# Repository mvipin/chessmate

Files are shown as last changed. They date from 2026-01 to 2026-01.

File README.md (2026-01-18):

# ChessMate - ROS2 Chess Robot






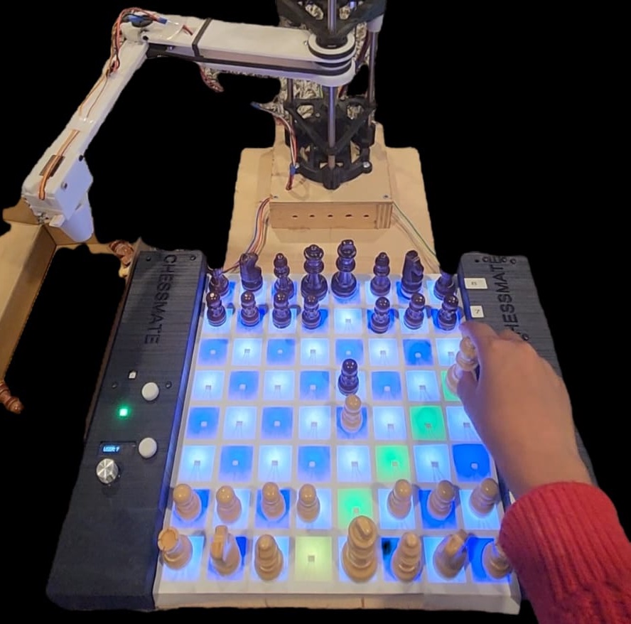
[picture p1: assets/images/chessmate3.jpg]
ChessMate Robot


**An AI chess master with expressive eyes, custom electronics, and a precision arm that will checkmate you with style!**

ChessMate is a fully autonomous chess-playing robot that physically moves pieces on a real chessboard. Built with ROS2, it combines professional-grade chess AI (Stockfish), custom electronics with home-fabricated PCBs, a 3-DOF SCARA robotic arm, and expressive animatronics to create an engaging chess opponent with personality.

## Introduction

### Key Features

| Category | Features |
|---|---|
| **Chess Intelligence** | Stockfish engine integration (skill levels 1-20), real-time move validation, FEN notation tracking, position analysis |
| **Robotic Precision** | 3-DOF SCARA arm (θ1 base, θ2 shoulder, Z height), sub-millimeter positioning accuracy, adaptive gripping, four-corner calibration |
| **Board Sensing** | 64 hall effect sensors, custom CNC-fabricated PCBs, 8×8 NeoPixel LED matrix, real-time move detection |
| **User Interface** | OLED display with rotary encoder, expressive servo-driven eyes, text-to-speech synthesis |
| **Architecture** | Three-controller distributed design (Pi + 2× Pico), topic-based ROS2 communication, mock/real mode support |

---

## Table of Contents

- [Introduction](#introduction)
- [Hardware Architecture](#hardware-architecture)
  - [PCB Design](#pcb-design)
  - [SCARA Arm](#scara-arm)
  - [Animatronics Head](#animatronics-head)
  - [Peripherals](#peripherals)
- [Software Architecture](#software-architecture)
  - [ROS2 Nodes](#ros2-nodes)
    - [chess_engine_server](#chess_engine_server)
    - [arduino_communication](#arduino_communication)
    - [game_management](#game_management)
  - [Active Topics](#active-topics)
  - [Serial Protocol](#serial-protocol)
- [Controllers](#controllers)
  - [ChessBoard Controller](#chessboard-controller)
  - [Robot Controller](#robot-controller)
- [Communication Flow](#communication-flow)
  - [Game Flow State Machine](#game-flow-state-machine)
  - [System Interaction Flows](#system-interaction-flows)
    - [System Initialization Flow](#system-initialization-flow)
    - [Computer Move Execution Flow](#computer-move-execution-flow)
    - [Human Move Detection Flow](#human-move-detection-flow)
    - [LCD Display and Menu Operation Flow](#lcd-display-and-menu-operation-flow)
    - [Robot Animatronics Flow](#robot-animatronics-flow)
- [Getting Started](#getting-started)
- [Testing](#testing)
  - [Overview](#overview)
  - [Test Levels](#test-levels)
  - [Running Tests](#running-tests)
  - [Monitoring & Diagnostics](#monitoring--diagnostics)
  - [Diagnostic Session Example](#diagnostic-session-example)
  - [Troubleshooting](#troubleshooting)
- [Continuous Integration](#continuous-integration)

---

## Hardware Architecture

ChessMate uses a distributed three-controller architecture. Each controller handles specific responsibilities, communicating via serial protocols.

| Controller | Role | Responsibilities |
|---|---|---|
| **Raspberry Pi** | The Brain | Chess engine integration and move calculation, game state management and rule enforcement, audio processing for speech and sound effects, system-wide coordination and safety oversight |
| **Board Controller** | The Senses | Real-time monitoring of all 64 chess piece positions, visual feedback through LED matrix, user interface management (OLED, buttons, rotary encoder), move detection and validation, player interaction handling |
| **Mechanical Controller** | The Body | Precision robotic arm movement control, adaptive gripper operation for different pieces, animatronic facial expressions and eye movements, safety systems and emergency stop coordination, real-time motion execution |

The diagram below shows the physical hardware components and their connections. The Raspberry Pi serves as the central brain, communicating with two Pi Pico microcontrollers via USB serial at 9600 baud. The Board Controller handles all sensing and user interface components, while the Mechanical Controller manages actuation and motion.

```mermaid
graph TB
    subgraph "Raspberry Pi - Main Brain"
        A[Stockfish Engine]
        B[Game Management]
        C[Audio Processing]
    end

    subgraph "Board Controller - Pi Pico"
        D[64 Hall Effect Sensors]
        E[8x8 NeoPixel LED Matrix]
        F[OLED Display + Rotary Encoder]
    end

    subgraph "Mechanical Controller - Pi Pico"
        G[Stepper Motors - Arm]
        H[Servo Motors - Gripper/Eyes]
        I[Limit Switches - Safety]
    end

    A <--> B
    B <--> C
    B <-->|"/dev/ttyACM0 @ 9600 baud"| D
    B <-->|"/dev/ttyACM1 @ 9600 baud"| G
    D --> E
    D --> F
    G --> H
    G --> I
```

### PCB Design

Custom CNC-fabricated PCBs provide the foundation for the chessboard sensing system.

| Specification | Value |
|---|---|
| Sensors | 64 hall effect sensors arranged in 8×8 grid |
| Interface | I2C expanders for efficient GPIO usage |
| Fabrication | CNC-milled PCBs with custom routing |
| Calibration | Baseline recording with threshold-based detection |

**Sensor Calibration:** Place pieces in starting positions → record baseline → set detection thresholds → validate all squares.

#### Chessboard Visuals

| CAD Rendering | Fabricated Chessboard |
|:---:|:---:|
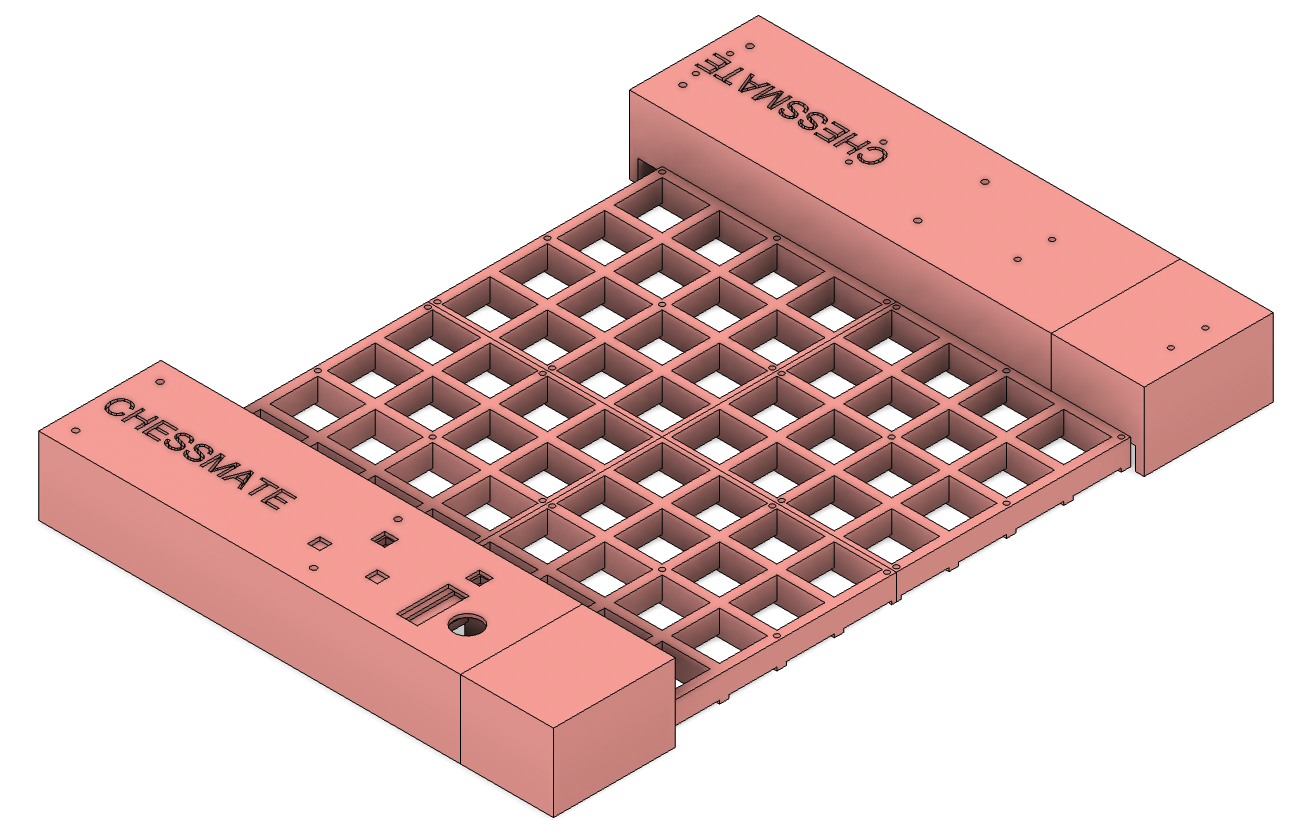
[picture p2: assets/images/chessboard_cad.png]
Chessboard CAD
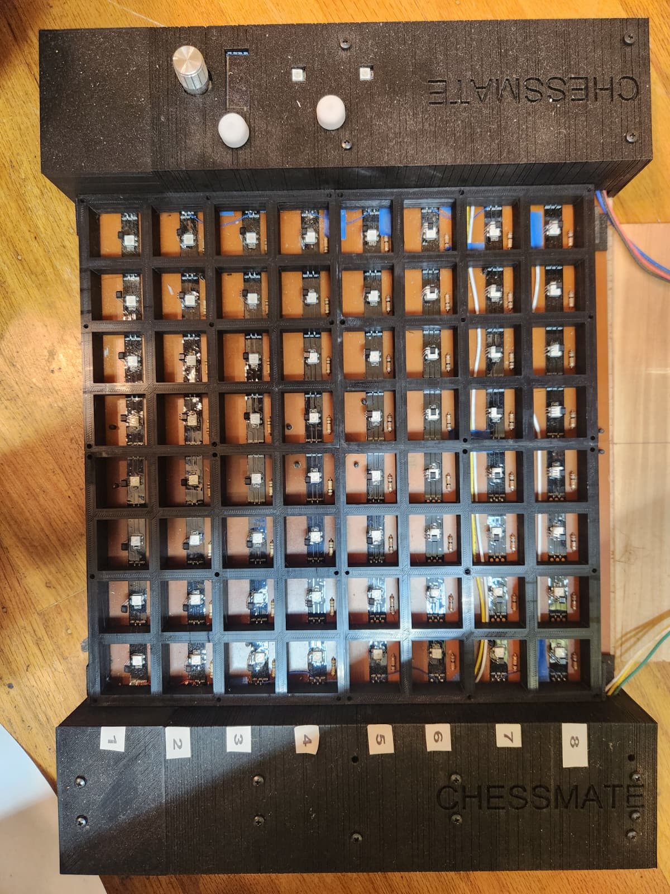
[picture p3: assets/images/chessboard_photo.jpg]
Chessboard Photo
|  |  |
| *3D CAD model showing board layout and sensor placement* | *Assembled chessboard with LED matrix and piece detection* |

| CNC Isolation-Milled PCB |
|:------------------------:|
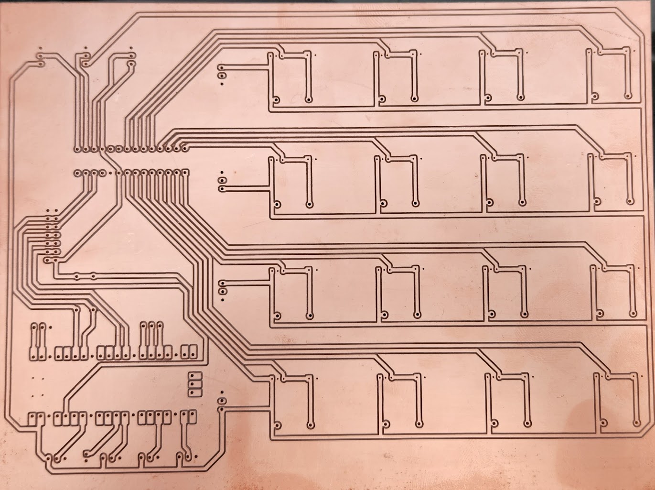
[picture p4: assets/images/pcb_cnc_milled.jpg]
PCB Photo
|  |
| *Custom PCB with hall effect sensors created using CNC isolation milling* |

<!--
TODO: Add actual image files to assets/images/ directory:
- chessboard_cad.png: CAD rendering of complete chessboard design
- chessboard_photo.jpg: Photo of assembled/fabricated chessboard
- pcb_cnc_milled.jpg: Close-up photo of CNC isolation-milled PCB with hall effect sensors
-->

### SCARA Arm

The 3-DOF SCARA (Selective Compliance Assembly Robot Arm) provides precise piece manipulation across the entire chessboard using two rotational joints plus one linear axis.

| Specification | Value |
|---|---|
| Arm Type | 3-DOF SCARA |
| Joint 1 (θ1) | Base rotation - positions arm radially |
| Joint 2 (θ2) | Shoulder rotation - extends/retracts reach |
| Joint 3 (Z) | Vertical translation - raises/lowers entire arm |
| Workspace | Full 8×8 chessboard coverage |
| Repeatability | Sub-millimeter positioning accuracy |
| Actuation | NEMA 17 steppers with microstepping |
| Gripper | Servo-controlled adaptive gripping |

**Arm Calibration:** Home position via limit switches → four-corner board registration → 64-point square mapping → EEPROM storage.

#### SCARA Arm Visuals

| CAD Rendering | Assembled Arm |
|:---:|:---:|
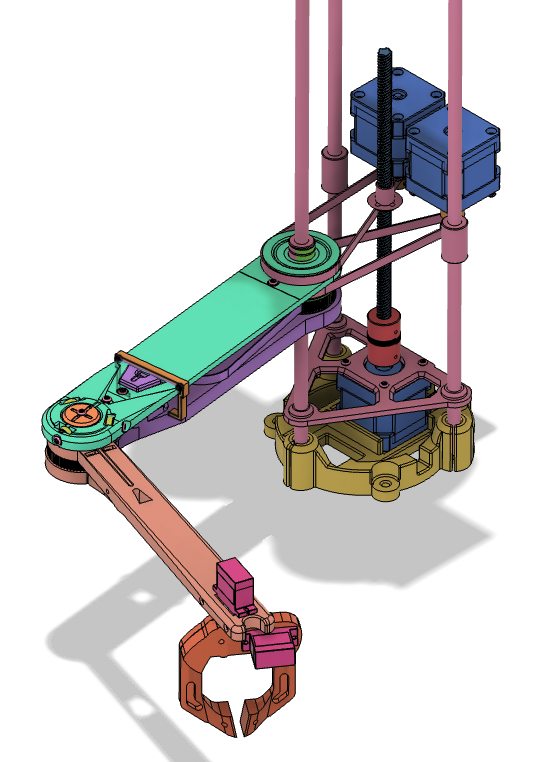
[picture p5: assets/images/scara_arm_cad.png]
SCARA CAD
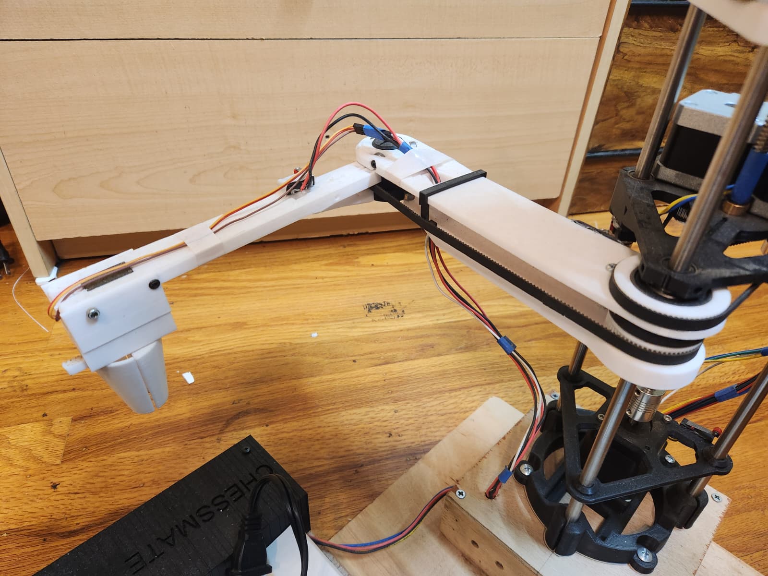
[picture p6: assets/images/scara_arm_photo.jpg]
SCARA Photo
|  |  |
| *3-DOF SCARA arm CAD model showing joint configuration* | *Assembled robotic arm mounted on chess platform* |

| Gripper Mechanism |
|:-----------------:|
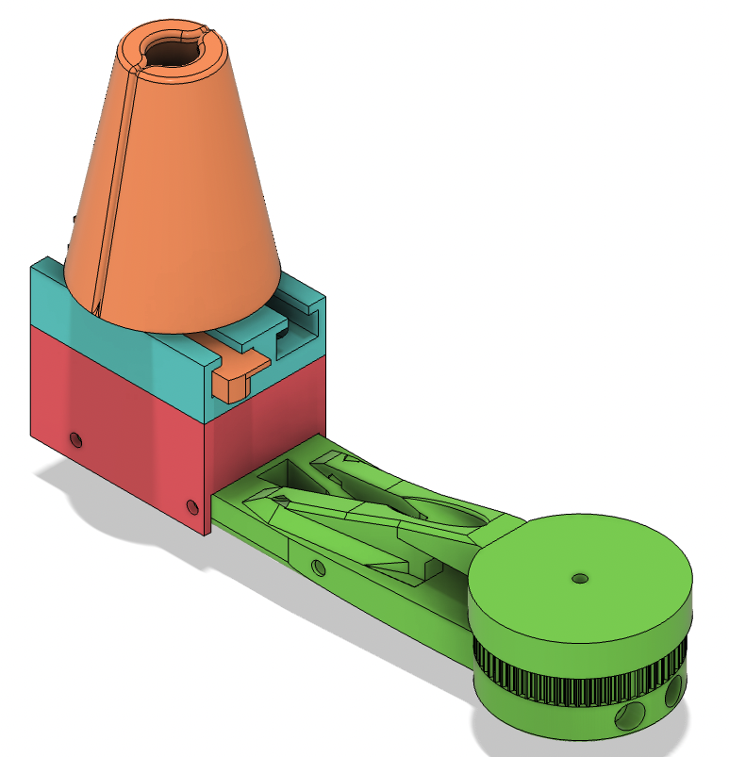
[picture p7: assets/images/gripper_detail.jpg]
Gripper Detail
|  |
| *Adaptive gripper mechanism for handling different chess piece sizes* |

<!--
TODO: Add actual image files to assets/images/ directory:
- scara_arm_cad.png: CAD rendering showing 3-DOF arm design and joint layout
- scara_arm_photo.jpg: Photo of fully assembled robotic arm
- gripper_detail.jpg: Close-up photo of gripper mechanism
-->

### Animatronics Head

Servo-driven expressive eyes and facial movements create an engaging opponent with personality.

| Component | Description |
|---|---|
| Eyes | Servo-driven with pan/tilt movement |
| Expressions | Victory, thinking, surprise, satisfaction |
| Controllers | Dual Pi Pico microcontrollers |

#### Animatronics Head Visuals

| CAD Rendering | Assembled Head |
|:---:|:---:|
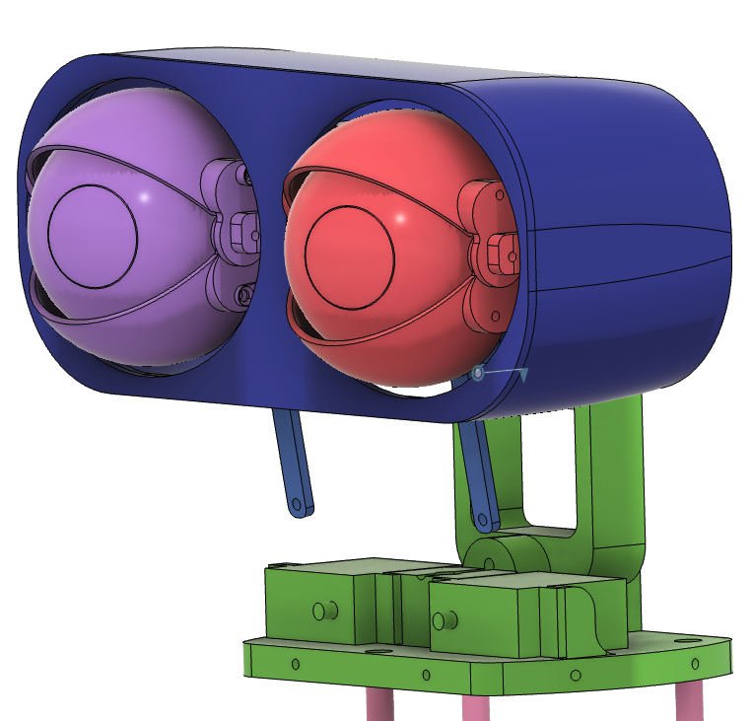
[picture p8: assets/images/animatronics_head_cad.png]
Head CAD
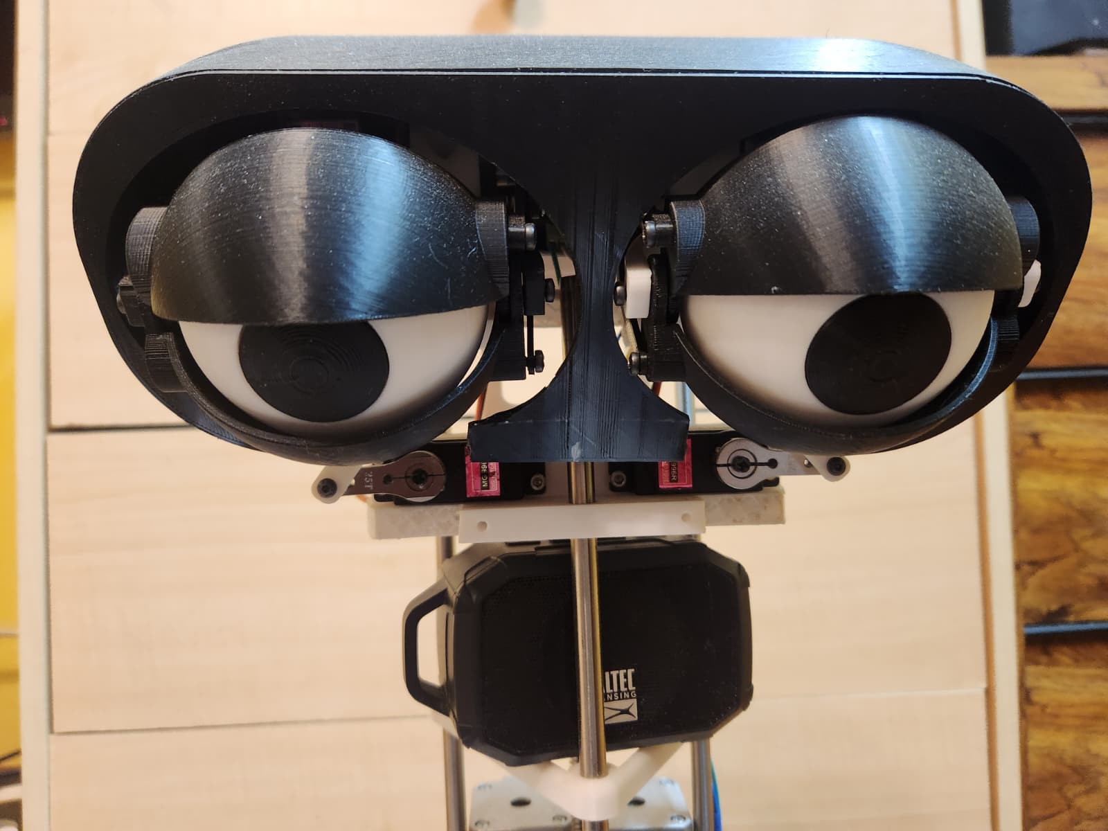
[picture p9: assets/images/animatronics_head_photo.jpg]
Head Photo
|  |  |
| *Expressive head CAD model with servo mounting points* | *Assembled animatronics head with expressive features* |

| Eye Mechanism Detail |
|:--------------------:|
| Eye Mechanism |
| *Servo-driven eye movement mechanism with pan/tilt capability* |

<!--
TODO: Add actual image files to assets/images/ directory:
- animatronics_head_cad.png: CAD rendering of expressive head design
- animatronics_head_photo.jpg: Photo of assembled head with servo-driven eyes
- eye_mechanism_detail.jpg: Close-up photo showing eye movement mechanism
-->

### Peripherals

User interface and feedback components managed by the Board Controller.

| Component | Description |
|---|---|
| Display | 8×8 NeoPixel LED matrix for move visualization |
| OLED | SSD1306 display for menu and game status |
| Input | Rotary encoder with push button |
| Audio | Text-to-speech synthesis via Raspberry Pi |

For detailed hardware documentation, CAD files, and schematics: [Hackaday Project](https://hackaday.io/project/203400-chessmate-ros2-chess-robot)

---

## Software Architecture

The diagram below illustrates the topic-based communication between ROS2 nodes. The game_management node orchestrates all game logic, requesting move calculations from chess_engine_server and dispatching physical moves to arduino_communication. Human moves detected by the board sensors flow back through the communication node to the game manager.

```mermaid
graph LR
    subgraph "Production Nodes"
        GM[game_management]
        CE[chess_engine_server]
        AC[arduino_communication]
    end

    GM -->|"/engine/calculate_move_request"| CE
    CE -->|"/engine/calculate_move_response"| GM
    GM -->|"/robot/execute_move_request"| AC
    AC -->|"/robot/execute_move_response"| GM
    AC -->|"/game/human_move"| GM
    GM -->|"/chessboard/set_mode_request"| AC
    AC -->|"/chessboard/set_mode_response"| GM
    GM -->|"/game/state"| EXT[External Monitors]
```

### ROS2 Nodes

ChessMate uses three production nodes that work together to orchestrate complete chess games:

#### chess_engine_server

Stockfish chess engine integration providing move calculation and position evaluation.

| Property | Value |
|---|---|
| **Package** | `chessmate` |
| **Executable** | `chess_engine_server.py` |
| **Launch** | `ros2 run chessmate chess_engine_server.py` |

**Topics:**
| Topic | Direction | Type | Description |
|---|---|---|---|
| `/engine/calculate_move_request` | Subscribe | `String` | FEN position with parameters |
| `/engine/calculate_move_response` | Publish | `String` | Best move and evaluation |

**Parameters:**
| Parameter | Default | Description |
|---|---|---|
| `stockfish_path` | `/usr/games/stockfish` | Path to Stockfish binary |
| `default_skill_level` | `10` | Engine skill (1-20) |
| `default_time_limit` | `5.0` | Thinking time in seconds |

#### arduino_communication

Serial communication interface with Pi Pico microcontrollers for board sensing and robot control.

| Property | Value |
|---|---|
| **Package** | `chessmate` |
| **Executable** | `arduino_communication.py` |
| **Launch** | `ros2 run chessmate arduino_communication.py` |

**Topics:**
| Topic | Direction | Type | Description |
|---|---|---|---|
| `/game/human_move` | Publish | `String` | Detected human moves (UCI format) |
| `/robot/execute_move_request` | Subscribe | `String` | Robot movement commands |
| `/robot/execute_move_response` | Publish | `String` | Robot movement confirmations |
| `/chessboard/set_mode_request` | Subscribe | `String` | Chessboard mode commands |
| `/chessboard/set_mode_response` | Publish | `String` | Chessboard mode confirmations |

**Parameters:**
| Parameter | Default | Description |
|---|---|---|
| `chessboard_port` | `/dev/ttyACM0` | Serial port for board controller |
| `robot_port` | `/dev/ttyACM1` | Serial port for robot controller |
| `baud_rate` | `9600` | Serial communication baud rate |
| `hardware_mode` | `mock` | Operating mode (`mock` or `real`) |

#### game_management

Game orchestration node managing turn-taking, move validation, and game state.

| Property | Value |
|---|---|
| **Package** | `chessmate` |
| **Executable** | `game_management.py` |
| **Launch** | `ros2 run chessmate game_management.py` |

**Topics:**
| Topic | Direction | Type | Description |
|---|---|---|---|
| `/game/state` | Publish | `GameState` | Current game status and board position |
| `/game/control` | Subscribe | `String` | Game control commands |
| `/game/human_move` | Subscribe | `String` | Human moves from chessboard |
| `/engine/calculate_move_request` | Publish | `String` | Engine calculation requests |
| `/engine/calculate_move_response` | Subscribe | `String` | Engine calculation responses |
| `/robot/execute_move_request` | Publish | `String` | Robot movement commands |
| `/robot/execute_move_response` | Subscribe | `String` | Robot movement confirmations |

**Parameters:**
| Parameter | Default | Description |
|---|---|---|
| `hardware_mode` | `mock` | Operating mode (`mock` or `real`) |
| `auto_start` | `true` | Auto-start game on initialization |
| `skill_level` | `10` | Stockfish skill level (1-20) |
| `time_limit` | `5.0` | Engine thinking time in seconds |

### Active Topics

| Topic | Type | Description |
|---|---|---|
| `/game/state` | GameState | Current game status and board position |
| `/game/control` | String | Game control commands (start, pause, reset) |
| `/game/human_move` | String | Detected human moves from chessboard (UCI format) |
| `/engine/calculate_move_request` | String | Engine calculation requests (FEN position) |
| `/engine/calculate_move_response` | String | Engine responses (best move + evaluation) |
| `/robot/execute_move_request` | String | Robot movement commands (6-char format) |
| `/robot/execute_move_response` | String | Robot movement confirmations |

### Serial Protocol

**ChessBoard Controller (/dev/ttyACM0):**
```
Host → Board: "mode:real\n" | "mode:mock\n" | "legal:e2e4,d2d4,g1f3\n"
Board → Host: "e2e4\n" (4-character UCI move)
```

**Robot Controller (/dev/ttyACM1):**
```
Host → Robot: "mode:real\n" | "mode:mock\n" | "move:e2pe4p\n"
Robot → Host: "ACK: Executing move\n" → "DONE: Move complete\n"

6-Character Move Format: [from_square][piece][to_square][dest_piece]
Examples: e2pe4p (pawn e2→e4), g1nf3n (knight g1→f3), e1kg1k (castling)
```

---

## Controllers

The ChessMate system uses two Pi Pico microcontrollers that handle sensing, actuation, and user interface components. Both controllers communicate with the Raspberry Pi host via USB serial at 9600 baud.

### ChessBoard Controller

The ChessBoard Controller manages board sensing, LED matrix display, and user interface components.

#### Features

| Feature | Description |
|---|---|
| Board Sensing | Hall effect sensors detect piece positions on all 64 squares |
| LED Matrix Display | 8×8 RGB LED matrix (WS2812B/NeoPixel) for move highlighting and game status |
| User Interface | Status LEDs for human/computer turn indicators, buttons for move confirmation and hints |
| Mock Mode | Runtime mode selection with intelligent move simulation (2-8 second timing) |

#### Hardware Configuration

| Component | Specification |
|---|---|
| Microcontroller | Raspberry Pi Pico (RP2040) |
| LED Matrix | 8×8 RGB (WS2812B/NeoPixel) |
| Sensors | 64 hall effect sensors (one per square) |
| Communication | Serial1 (GPIO 0/1) to Raspberry Pi |

#### Pin Configuration

| Pin | Function |
|-----|---|
| GPIO 0 | Serial1 TX (to Raspberry Pi) |
| GPIO 1 | Serial1 RX (from Raspberry Pi) |
| USB | Debug output (Serial monitor) |

#### Command Protocol

**Mode Commands:**
```
mode:real    - Enable real hardware mode
mode:mock    - Enable mock simulation mode
```

**Game Commands:**
| Command | Description |
|---|---|
| `init` | Initialize board for new game |
| `occupancy:pos1:pos2:...` | Set initial piece positions |
| `legal:move1:move2:...` | Set legal moves for current position |
| `hint:move` | Set hint move to display |
| `check:square1:square2:...` | Highlight check squares |
| `start` | Begin human turn |
| `comp:move` | Execute computer move |
| `override:move` | Override/undo move |
| `checkmate:king_pos:move` | Display checkmate |
| `reset` | Reset board state |

**Responses:**
| Response | Description |
|---|---|
| `e2e4` | 4-character move notation |
| `ffff` | Hint override signal |

### Robot Controller

The Robot Controller manages the robotic arm that executes computer chess moves, including stepper motors, gripper servo, and animatronics.

#### Features

| Feature | Description |
|---|---|
| USB Serial Communication | Direct communication with Raspberry Pi host via `/dev/ttyACM1` |
| Move Execution | Handles 6-character chess move commands (e.g., `e2pe4p`) |
| State Management | Tracks robot state (IDLE, MOVING, HOMING, etc.) |
| Mock Mode | Software simulation for testing (3-8 second move timing) |

#### Hardware Configuration

| Component | Specification |
|---|---|
| Microcontroller | Raspberry Pi Pico (RP2040) |
| Stepper Motors | 3-axis (X, Y, Z) with shared enable |
| Gripper | Servo-controlled |
| Safety | Limit switches on all axes |

#### Pin Configuration

| Pin | Function |
|-----|---|
| GPIO 2 | X-Axis Step |
| GPIO 3 | Y-Axis Step |
| GPIO 4 | Z-Axis Step |
| GPIO 5 | X-Axis Direction |
| GPIO 6 | Y-Axis Direction |
| GPIO 7 | Z-Axis Direction |
| GPIO 8 | Stepper Enable (shared) |
| GPIO 9 | X-Axis Limit Switch |
| GPIO 10 | Y-Axis Limit Switch |
| GPIO 11 | Z-Axis Limit Switch |
| GPIO 13 | Gripper Servo |
| USB | Communication to Raspberry Pi |

#### Command Protocol

**Mode Commands:**
```
mode:mock    - Enable mock simulation mode
mode:real    - Enable real hardware mode
```

**System Commands:**
| Command | Description |
|---|---|
| `init` | Initialize robot systems |
| `home` | Home robot to origin position |
| `status` | Get current robot status |

**Move Commands:**

Format: `<from><piece><to><dest_piece>` (6 characters)

| Field | Description |
|---|---|
| `from` | Source square (e.g., `e2`) |
| `piece` | Piece type (`p`=pawn, `r`=rook, `n`=knight, `b`=bishop, `q`=queen, `k`=king) |
| `to` | Destination square (e.g., `e4`) |
| `dest_piece` | Piece type at destination (same as source, or `x` for capture) |

**Single Character Commands:**
| Command | Description |
|---|---|
| `i` | Wake up robot (start animations) |
| `s` | Sleep robot (idle animations) |
| `j` | Home Z-axis only |
| `z` | Home all axes |

**Response Format:**
```
ROBOT: <message>
```

---

## Communication Flow

This section describes the dynamic behavior of the system, including state transitions, message flows, and interaction patterns between components.

### Game Flow State Machine

The state machine below shows the complete game flow from initialization through game completion. The system waits for human moves, validates them against legal move lists, calculates computer responses using Stockfish, and executes physical piece movements. The cycle continues until checkmate, stalemate, or resignation.

```mermaid
stateDiagram-v2
    [*] --> Initialization
    Initialization --> WaitingForHuman: Game Started
    WaitingForHuman --> ValidatingMove: Human Move Detected
    ValidatingMove --> WaitingForHuman: Invalid Move
    ValidatingMove --> ComputerThinking: Valid Move
    ComputerThinking --> ExecutingMove: Best Move Calculated
    ExecutingMove --> WaitingForHuman: Move Complete
    ValidatingMove --> GameOver: Checkmate/Stalemate
    ComputerThinking --> GameOver: Checkmate/Stalemate
    GameOver --> [*]
```

### System Interaction Flows

The following sequence diagrams illustrate detailed interaction patterns between system components for different workflows.

#### System Initialization Flow

The sequence diagram below shows the startup sequence when launching the ChessMate system. The game_management node coordinates initialization across all controllers, setting operating modes and preparing for gameplay.

```mermaid
sequenceDiagram
    participant GM as game_management<br/>(Raspberry Pi)
    participant CE as chess_engine_server<br/>(Raspberry Pi)
    participant AC as arduino_communication<br/>(Raspberry Pi)
    participant BC as Board Controller<br/>(Pi Pico)
    participant RC as Robot Controller<br/>(Pi Pico)

    Note over GM,RC: System Startup Sequence

    GM->>CE: Initialize Stockfish engine
    CE-->>GM: Engine ready (skill level set)

    GM->>AC: /chessboard/set_mode_request<br/>"mode:real"
    AC->>BC: Serial: "mode:real\n"
    BC-->>AC: "MODE: Real hardware mode enabled"
    AC-->>GM: /chessboard/set_mode_response

    GM->>AC: /robot/execute_move_request<br/>"mode:real"
    AC->>RC: Serial: "mode:real\n"
    RC-->>AC: "MODE: Real hardware mode enabled"
    AC-->>GM: /robot/execute_move_response

    GM->>AC: Send legal moves for white
    AC->>BC: Serial: "legal:e2e3,e2e4,d2d3..."
    BC-->>AC: "LEGAL: Set 20 legal moves"
    BC->>BC: Illuminate valid squares (LEDs)

    Note over GM,RC: System Ready - Human plays white
```

#### Computer Move Execution Flow

This diagram illustrates the complete workflow when the computer calculates and executes a chess move. The process includes engine thinking time (2-8 seconds), move transmission, and physical piece movement with animatronic feedback.

```mermaid
sequenceDiagram
    participant GM as game_management<br/>(Raspberry Pi)
    participant CE as chess_engine_server<br/>(Raspberry Pi)
    participant AC as arduino_communication<br/>(Raspberry Pi)
    participant RC as Robot Controller<br/>(Pi Pico)

    Note over GM,RC: Computer's Turn - After Human Move

    GM->>CE: /engine/calculate_move_request<br/>"rnbqkb1r/pppppppp/5n2/8/4P3/8/PPPP1PPP/RNBQKBNR w KQkq - 1 2|5.0|10"

    Note over CE: Stockfish thinking<br/>(2-8 seconds)

    CE-->>GM: /engine/calculate_move_response<br/>"d2d4|+0.35|depth:20"

    GM->>GM: Validate move & update board state

    GM->>AC: /robot/execute_move_request<br/>"move:d2pd4p"
    AC->>RC: Serial: "move:d2pd4p\n"
    RC-->>AC: "ACK: Executing move"

    Note over RC: Robot arm sequence:<br/>1. Move to d2<br/>2. Lower & grip pawn<br/>3. Lift piece<br/>4. Move to d4<br/>5. Lower & release

    RC->>RC: Execute eye animation<br/>(confident expression)

    RC-->>AC: "DONE: Move complete"
    AC-->>GM: /robot/execute_move_response<br/>"success"

    GM->>GM: Publish /game/state update
    GM->>AC: Send new legal moves for human

    Note over GM,RC: Human's Turn
```

#### Human Move Detection Flow

This diagram shows the process when a human player physically moves a piece on the chessboard. Hall effect sensors detect the movement, and the system validates and processes the move.

```mermaid
sequenceDiagram
    participant BC as Board Controller<br/>(Pi Pico)
    participant AC as arduino_communication<br/>(Raspberry Pi)
    participant GM as game_management<br/>(Raspberry Pi)

    Note over BC,GM: Human's Turn - Waiting for Move

    BC->>BC: Hall sensors detect piece lift<br/>from e2 (magnetic field change)
    BC->>BC: LED on e2 turns off

    Note over BC: Human moves piece...

    BC->>BC: Hall sensors detect piece place<br/>on e4 (magnetic field detected)
    BC->>BC: Validate against legal moves list

    alt Valid Move
        BC->>BC: LED on e4 confirms (green flash)
        BC->>AC: Serial: "e2e4\n"
        AC->>GM: /game/human_move<br/>"e2e4"
        GM->>GM: Apply move to board state
        GM->>GM: Check for checkmate/stalemate
        GM->>GM: Publish /game/state update
        Note over GM: Trigger computer's turn
    else Invalid Move
        BC->>BC: LED flash red warning
        BC->>BC: Wait for piece return
    end
```

#### LCD Display and Menu Operation Flow

This diagram demonstrates the user interface workflow for menu navigation and game control using the rotary encoder and OLED display on the Board Controller.

```mermaid
sequenceDiagram
    participant RE as Rotary Encoder<br/>(Board Controller)
    participant LCD as OLED Display<br/>(Board Controller)
    participant BC as Board Controller<br/>(Pi Pico)
    participant AC as arduino_communication<br/>(Raspberry Pi)
    participant GM as game_management<br/>(Raspberry Pi)

    Note over RE,GM: Menu Navigation

    RE->>BC: Rotation detected (CW)
    BC->>LCD: Update menu selection<br/>"▶ Skill Level: 10"

    RE->>BC: Rotation detected (CW)
    BC->>LCD: Update display<br/>"▶ Skill Level: 11"

    RE->>BC: Button press (select)
    BC->>AC: Serial: "config:skill:11\n"
    AC->>GM: /game/control<br/>"set_skill:11"
    GM->>GM: Update engine parameters
    GM-->>AC: Acknowledge
    AC-->>BC: "CONFIG: Skill set to 11"
    BC->>LCD: Display confirmation<br/>"✓ Skill Level: 11"

    Note over RE,GM: Game Control

    RE->>BC: Button long-press
    BC->>LCD: Show game menu<br/>"New Game / Resign / Settings"

    RE->>BC: Select "New Game"
    BC->>AC: Serial: "control:newgame\n"
    AC->>GM: /game/control<br/>"new_game"
    GM->>GM: Reset board state
    GM->>AC: Initialize new game
    BC->>LCD: Display "Game Started!<br/>Your move (White)"
```

#### Robot Animatronics Flow

This diagram shows how the robot expresses emotions and reactions through servo-driven eye movements and gestures during gameplay events.

```mermaid
sequenceDiagram
    participant GM as game_management<br/>(Raspberry Pi)
    participant RAC as robot_animation_controller<br/>(Raspberry Pi)
    participant AC as arduino_communication<br/>(Raspberry Pi)
    participant RC as Robot Controller<br/>(Pi Pico)
    participant Eyes as Servo Eyes<br/>(Hardware)

    Note over GM,Eyes: Game Event Triggers Animation

    GM->>RAC: Game event: "computer_winning"
    RAC->>RAC: Select animation sequence<br/>"confident_look"

    RAC->>AC: /robot/animation_request<br/>"eyes:confident"
    AC->>RC: Serial: "anim:confident\n"

    RC->>Eyes: Servo sequence:<br/>1. Eyes narrow slightly<br/>2. Slow deliberate blink<br/>3. Look at opponent

    RC-->>AC: "ANIM: Complete"
    AC-->>RAC: Animation acknowledged

    Note over GM,Eyes: Checkmate Celebration

    GM->>RAC: Game event: "checkmate_delivered"
    RAC->>RAC: Select animation sequence<br/>"victory_celebration"

    RAC->>AC: /robot/animation_request<br/>"eyes:victory"
    AC->>RC: Serial: "anim:victory\n"

    RC->>Eyes: Servo sequence:<br/>1. Eyes widen (surprise)<br/>2. Quick happy blinks<br/>3. Look down at board<br/>4. Satisfied expression

    RC->>RC: Optional: arm gesture<br/>(victory wave)

    RC-->>AC: "ANIM: Complete"
```

---

## Getting Started

### Prerequisites

| Requirement | Specification |
|---|---|
| OS | Ubuntu 22.04 LTS (Jammy) |
| ROS2 | Humble Hawksbill |
| Hardware | Raspberry Pi (4GB+ recommended) |
| Python | 3.10+ |
| Dependencies | `python-chess`, `stockfish`, `pyserial` |

### Quick Start

#### Existing Setup

```bash
# Navigate to workspace
cd ~/ChessMate-ROS2

# Source ROS2 environment
source /opt/ros/humble/setup.bash
source install/setup.bash

# Launch complete chess game system (mock mode)
./scripts/launch_production_game.sh --mode mock

# Launch with real hardware
./scripts/launch_production_game.sh --mode real

# Test package functionality
python3 -c "import rclpy, chess; print('✅ ChessMate packages ready!')"

# Run system tests
./scripts/test_chessmate_system.sh game --mode mock --duration 300
```

#### New Setup

```bash
git clone https://github.com/mvipin/ChessMate-ROS2.git
cd ChessMate-ROS2
sudo apt update && sudo apt install -y ros-humble-desktop python3-pip stockfish
pip3 install python-chess pyserial
./scripts/build.sh  # Auto-detects x86 or ARM platform
source /opt/ros/humble/setup.bash && source install/setup.bash
./scripts/test_controllers.sh
```

### Development Setup

See [ROS2 Conversion Roadmap](docs/ROS2_CONVERSION_ROADMAP.md).

---

## Testing

### Overview

ChessMate uses a multi-level testing approach that progresses from isolated controller tests to full system integration. Tests can run in mock mode (simulated hardware) or real mode (physical hardware connected).

### Test Levels

| Level | Description | Command |
|---|---|---|
| **Level 0** | Pi Pico controllers (no ROS2) | `./scripts/test_chessmate_system.sh pico --mode mock --controller both` |
| **Level 1** | ROS2 integration | `./scripts/test_chessmate_system.sh ros2 --mode mock --controller both` |
| **Level 2** | Complete chess game | `./scripts/test_chessmate_system.sh game --mode mock --duration 300` |

### Running Tests

**Test Scripts:**

| Script | Description |
|---|---|
| `test_chessmate_system.sh` | Main test launcher with menu-driven interface for all test levels |
| `test_complete_game.py` | Full game simulation with dual controller integration |
| `cleanup_chessmate_processes.sh` | Cleanup script for terminating test processes |

**test_chessmate_system.sh Options:**

| Option | Description |
|---|---|
| 1 | ChessBoard Controller only - Tests board sensing and human move detection |
| 2 | Robot Controller only - Tests robotic arm control and move execution |
| 3 | Complete game simulation - Full integration test with both controllers |
| 4-5 | Interactive modes - Manual testing with real-time command input |
| 6 | All tests (automated) - Runs complete test suite |

**test_complete_game.py Modes:**
```bash
python3 scripts/test_complete_game.py full        # Complete game simulation
python3 scripts/test_complete_game.py individual  # Individual controller tests
python3 scripts/test_complete_game.py init        # Game initialization only
```

**Common Commands:**
```bash
# Mock game simulation (5 minutes)
./scripts/test_chessmate_system.sh game --mode mock --duration 300

# Real hardware game
./scripts/test_chessmate_system.sh game --mode real --duration 600 --skill-level 10

# Cleanup between tests
./scripts/cleanup_chessmate_processes.sh

# Run automated test suite
./scripts/test_chessmate_system.sh  # Then choose option 6

# Help
./scripts/test_chessmate_system.sh --help
```

**Testing Workflow:**

*Development Testing:*
1. Test individual controllers first using their respective test options
2. Verify basic communication and command processing
3. Run integration tests using the main test launcher

*Integration Testing:*
1. Use `test_chessmate_system.sh` for comprehensive system testing
2. Start with individual controller tests (options 1-2)
3. Progress to complete game simulation (option 3)
4. Use interactive modes for debugging (options 4-5)

*Prerequisites:*
- ChessBoard Pi Pico connected via USB (`/dev/ttyACM0`)
- Robot Pi Pico connected via USB (`/dev/ttyACM1`) - optional for ChessBoard-only tests
- User in `dialout` group for USB device access
- Both controllers running appropriate firmware

### Monitoring & Diagnostics

**Real-Time Monitoring Commands:**
```bash
ros2 topic echo /game/state              # Game state
ros2 topic echo /game/human_move         # Human moves
ros2 topic echo /robot/execute_move_response  # Robot execution
rqt_graph                                 # System topology
```

**ROS2 Node Reference:**

| Node Name | Function |
|---|---|
| `/arduino_communication` | Hardware interface for chessboard and robot arm |
| `/chess_engine_server` | Stockfish-based move calculation |
| `/game_management` | Central game orchestration and state management |
| `/full_game_integration_test` | Test harness simulating human moves |

**ROS2 Topic Reference:**

*Game-Related Topics:*
| Topic | Type | Publisher | Subscriber(s) |
|---|---|---|---|
| `/game/state` | `chessmate/msg/GameState` | game_management | full_game_integration_test |
| `/game/control` | `std_msgs/msg/String` | full_game_integration_test | game_management |
| `/game/human_move` | `std_msgs/msg/String` | arduino_communication, test | game_management |

*Chess Engine Topics:*
| Topic | Type | Publisher | Subscriber |
|---|---|---|---|
| `/engine/calculate_move_request` | `std_msgs/msg/String` | game_management | chess_engine_server |
| `/engine/calculate_move_response` | `std_msgs/msg/String` | chess_engine_server | game_management |

*Robot Control Topics:*
| Topic | Type | Publisher | Subscriber |
|---|---|---|---|
| `/robot/execute_move_request` | `std_msgs/msg/String` | game_management | arduino_communication |
| `/robot/execute_move_response` | `std_msgs/msg/String` | arduino_communication | game_management |

*Chessboard Controller Topics:*
| Topic | Type | Publisher | Subscriber |
|---|---|---|---|
| `/chessboard/legal_moves` | `std_msgs/msg/String` | game_management | arduino_communication |
| `/chessboard/set_mode_request` | `std_msgs/msg/String` | game_management | arduino_communication |
| `/chessboard/set_mode_response` | `std_msgs/msg/String` | arduino_communication | game_management |

**Communication Graph:**

```mermaid
flowchart TB
    subgraph TestHarness["Test Harness"]
        TEST[full_game_integration_test]
    end

    subgraph GameOrchestration["Game Orchestration"]
        GM[game_management<br/>Central Orchestrator]
    end

    subgraph ChessAI["Chess AI"]
        ENGINE[chess_engine_server<br/>Stockfish]
    end

    subgraph Hardware["Hardware Interface"]
        ARDUINO[arduino_communication<br/>Robot + Chessboard]
    end

    %% Test to Game Management
    TEST -->|/game/control| GM
    TEST -->|/game/human_move| GM

    %% Game Management to Chess Engine
    GM -->|/engine/calculate_move_request| ENGINE
    ENGINE -->|/engine/calculate_move_response| GM

    %% Game Management to Arduino
    GM -->|/robot/execute_move_request| ARDUINO
    ARDUINO -->|/robot/execute_move_response| GM
    GM -->|/chessboard/legal_moves| ARDUINO
    GM -->|/chessboard/set_mode_request| ARDUINO
    ARDUINO -->|/chessboard/set_mode_response| GM
    ARDUINO -->|/game/human_move| GM

    %% Game State broadcast
    GM -->|/game/state| TEST

    %% Styling
    style GM fill:#4a90d9,stroke:#2c5aa0,color:#fff
    style ENGINE fill:#50c878,stroke:#3a9a5c,color:#fff
    style ARDUINO fill:#f5a623,stroke:#c7851a,color:#fff
    style TEST fill:#9b59b6,stroke:#7d3c98,color:#fff
```

### Diagnostic Session Example

This example shows a complete ROS2 system diagnostics session captured during an end-to-end ChessMate system test.

**Test Result**: ✅ SUCCESS - 15 moves played in ~3 minutes

**Test Execution Timeline:**

| Timestamp | Phase | Activity |
|---|---|---|
| 07:14:02 | Start | Test initialization |
| 07:14:14 | Init | Nodes discovered, first capture |
| 07:14:18 | Play | Game started, moves 1-4 |
| 07:15:07 | Play | Capture 1 - moves 5-6 |
| 07:15:46 | Play | Capture 2 - moves 7-10 |
| 07:16:27 | End | Capture 3 - test completed, nodes shutting down |
| 07:17:05 | Final | Final capture - all nodes terminated |

**Diagnostic Files Generated:**

| File | Description |
|---|---|
| [`system_test_output.log`](test/system/diagnostics/system_test_output.log) | Complete test execution log |
| [`topic_game_state.log`](test/system/diagnostics/topic_game_state.log) | Game state topic messages |
| [`topic_human_move.log`](test/system/diagnostics/topic_human_move.log) | Human move commands |
| [`topic_execute_move_response.log`](test/system/diagnostics/topic_execute_move_response.log) | Robot move confirmations |
| [`node_info.log`](test/system/diagnostics/node_info.log) | Detailed node pub/sub info |
| [`service_list.log`](test/system/diagnostics/service_list.log) | ROS2 services timeline |

**System Verification Checklist:**

✅ All ROS2 nodes initialized and communicated correctly
✅ Topic-based pub/sub communication working as designed
✅ Game orchestration properly coordinated all components
✅ Engine-robot-chessboard loop executed 15 complete turns
✅ Clean shutdown without message loss

### Troubleshooting

| Issue | Solutions |
|---|---|
| Controllers not found | Check USB connections, verify device paths (`/dev/ttyACM0`, `/dev/ttyACM1`), try different USB ports |
| Permission errors | Add user to dialout group: `sudo usermod -a -G dialout $USER`, then log out/in |
| Communication failures | Verify baud rate (9600), check controller firmware is running, try resetting controllers |
| Test failures | Run individual controller tests first, enable debug mode in controller firmware |
| Timeout errors | Ensure controllers are not busy, check for responsive controller state |

---

## Continuous Integration

ChessMate uses Jenkins for automated testing on every push to `main`.

| Stage | Description | Status |
|---|---|---|
| Build | ROS2 colcon build | ✅ |
| Unit Tests | 41 pytest tests (kinematics, chess logic, coordinate mapping) | ✅ |
| Integration Tests | ROS2 node communication tests | On PR/main |
| Hardware Tests | Physical hardware validation | Manual trigger |

**Pipeline Configuration:** See [`Jenkinsfile`](Jenkinsfile) for full pipeline definition.

**Local Test Execution:**
```bash
source ~/ChessMate/chessmate_env/bin/activate
python3 -m pytest test/unit/ -v
```

---

## Contributing

1. Fork and create a feature branch: `git checkout -b feature/your-feature`
2. Follow ROS2 coding standards and Python PEP 8
3. Add tests and run: `./scripts/test_chessmate_system.sh game --mode mock --duration 300`
4. Submit a pull request with clear description

---

## License

MIT License - see [LICENSE](LICENSE) file.

---

## Acknowledgments

Thanks to the ROS2 Community, Stockfish Team, Raspberry Pi Foundation, and Hackaday Community.

---

**Links:** [GitHub](https://github.com/mvipin/ChessMate-ROS2) | [Hackaday](https://hackaday.io/project/203400-chessmate-ros2-chess-robot) | [Issues](https://github.com/mvipin/ChessMate-ROS2/issues)

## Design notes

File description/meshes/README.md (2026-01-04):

# SCARA Robot Mesh Export Guide

## Fusion 360 STL Export Instructions

### **Step 1: Prepare Your F360 Model**
1. Ensure each component is properly named:
   - Base → `base_link`
   - First arm → `link1` 
   - Second arm → `link2`
   - End effector → `end_effector`

### **Step 2: Export Visual Meshes (High Detail)**
For each component:
1. Right-click the component in the browser
2. Select "Save As Mesh"
3. Choose STL format
4. Set refinement to **Medium** or **High**
5. Save to `visual/` folder with naming:
   - `base_link_visual.stl`
   - `link1_visual.stl`
   - `link2_visual.stl`
   - `end_effector_visual.stl`

### **Step 3: Export Collision Meshes (Low Detail)**
For each component:
1. Right-click the component in the browser
2. Select "Save As Mesh"
3. Choose STL format
4. Set refinement to **Low** or **Medium**
5. Save to `collision/` folder with naming:
   - `base_link_collision.stl`
   - `link1_collision.stl`
   - `link2_collision.stl`
   - `end_effector_collision.stl`

### **Step 4: Enable Meshes in URDF**
Once STL files are exported, edit the URDF:
```xml
<xacro:property name="use_meshes" value="true" />
```

## File Structure
```
meshes/
├── visual/           # High-detail meshes for visualization
│   ├── base_link_visual.stl
│   ├── link1_visual.stl
│   ├── link2_visual.stl
│   └── end_effector_visual.stl
├── collision/        # Low-detail meshes for collision detection
│   ├── base_link_collision.stl
│   ├── link1_collision.stl
│   ├── link2_collision.stl
│   └── end_effector_collision.stl
└── README.md
```

## Coordinate System Notes
- F360 exports in mm, URDF uses meters (scale factor: 0.001)
- Ensure F360 coordinate system matches URDF expectations
- X-axis should point forward along the link
- Z-axis should point up for the base

## Quality Settings
- **Visual meshes**: Medium/High detail for realistic appearance
- **Collision meshes**: Low detail for performance
- **File size**: Keep visual meshes under 1MB each if possible

## Testing
After exporting:
1. Set `use_meshes="true"` in the URDF
2. Rebuild: `colcon build --packages-select chessmate_description`
3. Launch: `ros2 launch chessmate_description display.launch.py`
4. Verify meshes load correctly in RViz2

## Troubleshooting
- **Mesh not visible**: Check file paths and scaling
- **Wrong orientation**: Verify F360 coordinate system
- **Performance issues**: Use lower detail collision meshes
- **File not found**: Ensure meshes are installed with `colcon build`

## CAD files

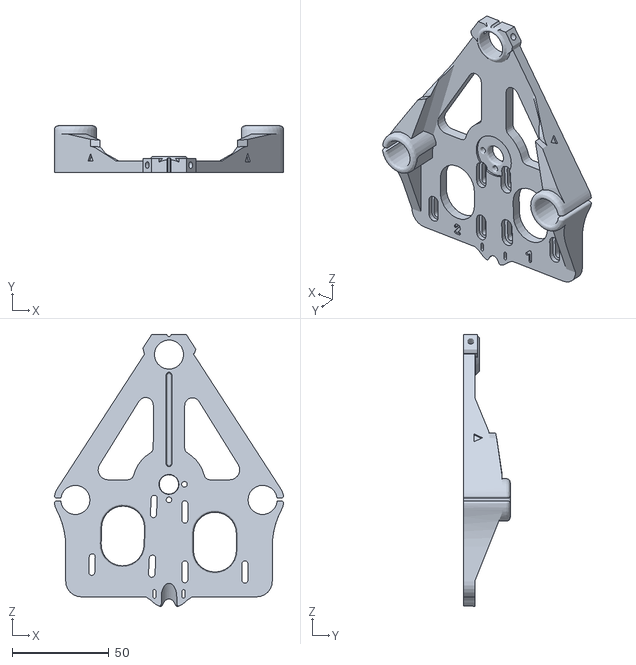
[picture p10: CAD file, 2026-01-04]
description/meshes/collision/base_link_collision.stl
118.3 x 24.0 x 140.4

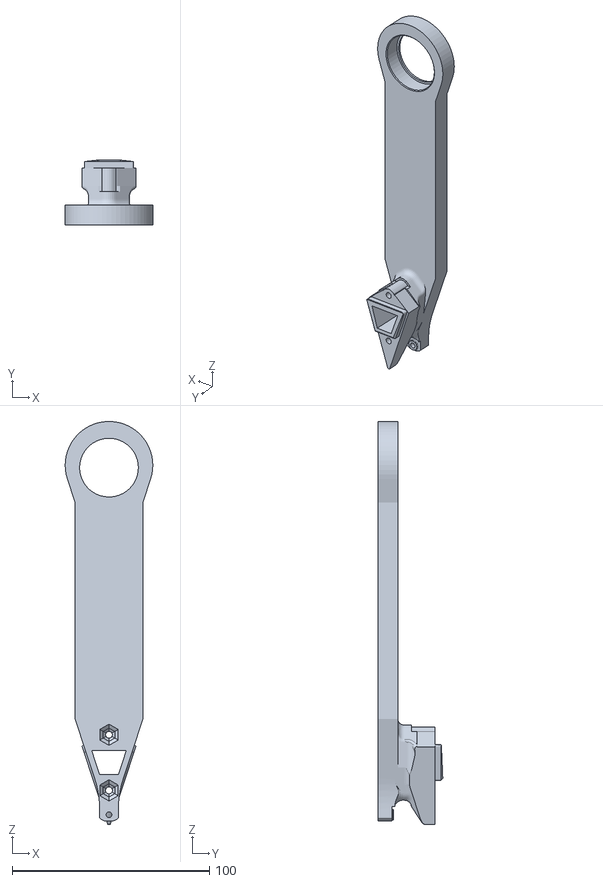
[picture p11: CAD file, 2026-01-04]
description/meshes/visual/link1_visual.stl
44.5 x 32.8 x 204.5

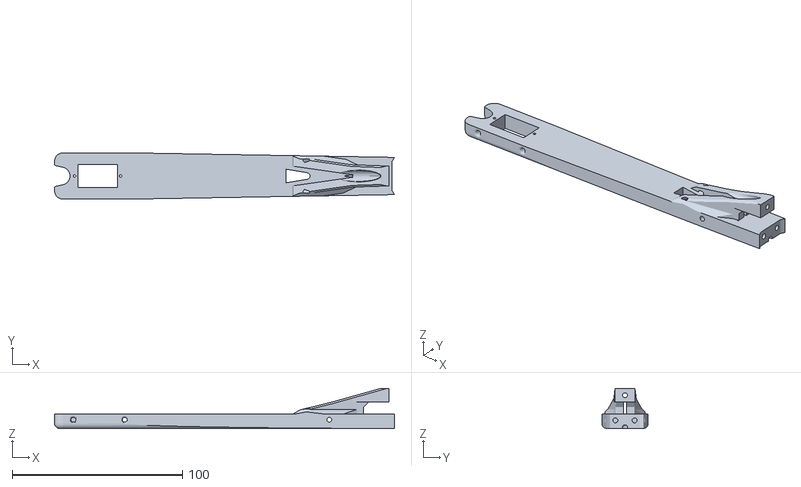
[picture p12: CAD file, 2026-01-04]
description/meshes/collision/link2_collision.stl
199.6 x 27.2 x 23.5

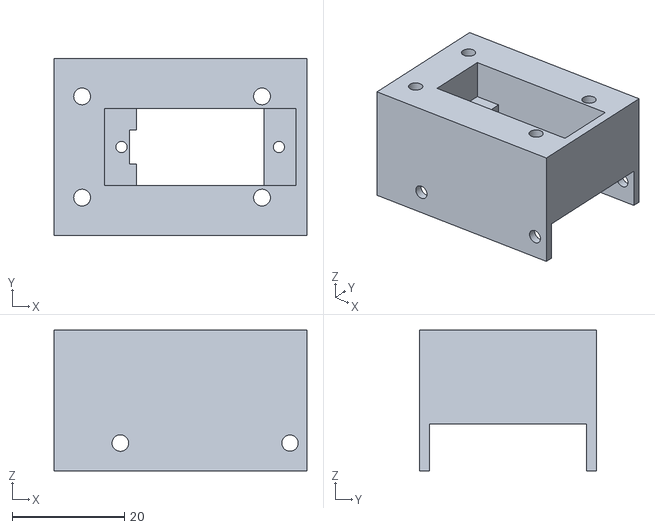
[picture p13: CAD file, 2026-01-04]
description/meshes/visual/end_effector_visual.stl
45.0 x 31.5 x 25.0

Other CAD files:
description/meshes/visual/link2_visual.stl
description/meshes/collision/link1_collision.stl
description/meshes/collision/end_effector_collision.stl
description/meshes/visual/base_link_visual.stl

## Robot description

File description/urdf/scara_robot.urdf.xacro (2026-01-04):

<?xml version="1.0"?>
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
<robot xmlns:xacro="http://www.ros.org/wiki/xacro" name="chessmate_scara">

  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
  <xacro:property name="link1_length" value="0.202" />
  <xacro:property name="link2_length" value="0.190" />
  <xacro:property name="link1_width" value="0.044" />
  <xacro:property name="link2_width" value="0.022" />
  <xacro:property name="base_height" value="0.1" />

  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
  <xacro:property name="use_meshes" value="true" />

  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
  <xacro:property name="mesh_path" value="package://chessmate_description/meshes" />

  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
  <link name="world"/>

  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
  <joint name="world_to_base" type="fixed">
    <parent link="world"/>
    <child link="base_link"/>
    <origin xyz="0 0 0" rpy="0 0 0"/>
  </joint>

  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
  <link name="base_link">
    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
    <inertial>
      <mass value="2.0"/>
      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
    </inertial>
  </link>

  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
  <joint name="z_joint" type="prismatic">
    <parent link="base_link"/>
    <child link="z_carriage"/>
    <origin xyz="0 0 ${base_height/2}" rpy="0 0 0"/>
    <axis xyz="0 0 1"/>
    <limit lower="0" upper="0.1" effort="5" velocity="0.1"/>
  </joint>

  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
  <link name="z_carriage">
    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
    <inertial>
      <mass value="0.2"/>
      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
    </inertial>
  </link>

  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
  <joint name="base_joint" type="revolute">
    <parent link="z_carriage"/>
    <child link="link1"/>
    <origin xyz="0 0 0" rpy="0 0 0"/>
    <axis xyz="0 0 1"/>
    <limit lower="-1.57" upper="1.57" effort="10" velocity="2.0"/>
  </joint>

  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
  <link name="link1">
    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
    <inertial>
      <origin xyz="${link1_length/2} 0 0" rpy="0 0 0"/>
      <mass value="1.0"/>
      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
    </inertial>
  </link>

  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
  <joint name="coupling_joint" type="revolute">
    <parent link="link1"/>
    <child link="coupling_link"/>
    <origin xyz="${link1_length} 0 0" rpy="0 0 0"/>
    <axis xyz="0 0 1"/>
    <limit lower="-3.14" upper="3.14" effort="10" velocity="2.0"/>
    <mimic joint="base_joint" multiplier="-1.0" offset="0.0"/>
  </joint>

  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
  <link name="coupling_link">
    <inertial>
      <mass value="0.001"/>
      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
    </inertial>
  </link>

  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
  <joint name="shoulder_joint" type="revolute">
    <parent link="coupling_link"/>
    <child link="link2"/>
    <origin xyz="0 0 0" rpy="0 0 0"/>
    <axis xyz="0 0 1"/>
    <limit lower="-2.618" upper="2.618" effort="10" velocity="2.0"/>
    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
  </joint>

  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
  <link name="link2">
    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
    <inertial>
      <origin xyz="${link2_length/2} 0 0" rpy="0 0 0"/>
      <mass value="0.5"/>
      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
    </inertial>
  </link>

  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
  <joint name="end_effector_joint" type="fixed">
    <parent link="link2"/>
    <child link="end_effector"/>
    <origin xyz="${link2_length} 0 0" rpy="0 0 0"/>
  </joint>

  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
  <link name="end_effector">
    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
    <inertial>
      <mass value="0.1"/>
      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
    </inertial>
  </link>

</robot>

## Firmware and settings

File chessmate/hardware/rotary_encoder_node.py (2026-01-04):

#!/usr/bin/env python3
"""
Rotary Encoder ROS 2 Node for ChessMate

This node interfaces with the rotary encoder hardware and publishes
user input events to the ROS 2 system. It's based on the original
Rotary.py but adapted for ROS 2 architecture.
"""

import rclpy
from rclpy.node import Node
from rclpy.qos import QoSProfile, ReliabilityPolicy, DurabilityPolicy
import time
import threading
from typing import Optional

from chessmate.msg import RotaryEncoderEvent
from chessmate.hardware.gpio_abstraction import GPIOAbstraction, GPIOMode, GPIOPull, GPIOEdge


class RotaryEncoderNode(Node):
    """
    ROS 2 Node for handling rotary encoder input
    
    This node:
    - Interfaces with rotary encoder hardware (CLK, DT, BTN pins)
    - Publishes RotaryEncoderEvent messages for rotation and button events
    - Maintains encoder position state
    - Handles debouncing and calibration
    """
    
    def __init__(self):
        super().__init__('rotary_encoder_node')
        
        # Declare parameters
        self.declare_parameter('clk_pin', 11)
        self.declare_parameter('dt_pin', 12)
        self.declare_parameter('btn_pin', 13)
        self.declare_parameter('use_real_gpio', GPIOAbstraction.is_raspberry_pi())
        self.declare_parameter('publish_rate', 10.0)  # Hz
        
        # Get parameters
        self.clk_pin = self.get_parameter('clk_pin').value
        self.dt_pin = self.get_parameter('dt_pin').value
        self.btn_pin = self.get_parameter('btn_pin').value
        use_real_gpio = self.get_parameter('use_real_gpio').value
        
        self.get_logger().info(f"Rotary Encoder Node starting with pins: CLK={self.clk_pin}, DT={self.dt_pin}, BTN={self.btn_pin}")
        
        # Initialize GPIO abstraction
        try:
            self.gpio = GPIOAbstraction(use_real_gpio=use_real_gpio)
            self.get_logger().info(f'GPIO abstraction initialized - using real GPIO: {self.gpio.use_real_gpio}')
        except Exception as e:
            self.get_logger().error(f"Failed to initialize GPIO: {e}")
            raise
        
        # Encoder state variables (matching original Rotary.py logic)
        self.rotary_last_state = None
        self.btn_last_state = None
        self.clk_level = 0
        self.dt_level = 0
        self.calibrate = False
        self.encoder_position = 0
        self.button_pressed = False
        
        # Thread safety
        self.state_lock = threading.Lock()

        # Create publisher with appropriate QoS BEFORE setting up GPIO
        qos_profile = QoSProfile(
            reliability=ReliabilityPolicy.RELIABLE,
            durability=DurabilityPolicy.VOLATILE,
            depth=10
        )

        self.encoder_publisher = self.create_publisher(
            RotaryEncoderEvent,
            'rotary_encoder_events',
            qos_profile
        )

        # Setup GPIO pins AFTER publisher is created
        self._setup_gpio()
        
        # Create timer for periodic status updates
        publish_rate = self.get_parameter('publish_rate').get_parameter_value().double_value
        self.status_timer = self.create_timer(1.0 / publish_rate, self._publish_status)
        
        self.get_logger().info("Rotary Encoder Node initialized successfully")
    
    def _setup_gpio(self):
        """Setup GPIO pins and event detection"""
        try:
            # Setup pins
            self.gpio.setup_pin(self.clk_pin, GPIOMode.INPUT, GPIOPull.UP)
            self.gpio.setup_pin(self.dt_pin, GPIOMode.INPUT, GPIOPull.UP)
            self.gpio.setup_pin(self.btn_pin, GPIOMode.INPUT, GPIOPull.UP)
            
            # Add event detection with proper bouncetime
            self.get_logger().debug(f'Setting up GPIO event detection on pins CLK={self.clk_pin}, DT={self.dt_pin}, SW={self.btn_pin}')
            self.gpio.add_event_detect(self.clk_pin, GPIOEdge.BOTH, self._pulse_callback, bouncetime=50)
            self.gpio.add_event_detect(self.dt_pin, GPIOEdge.BOTH, self._pulse_callback, bouncetime=50)
            self.gpio.add_event_detect(self.btn_pin, GPIOEdge.FALLING, self._button_callback, bouncetime=300)
            self.get_logger().debug('GPIO event detection setup complete')
            
            # Initialize states
            with self.state_lock:
                self.rotary_last_state = None
                self.btn_last_state = self.gpio.read_pin(self.btn_pin)
                self.button_pressed = not self.btn_last_state  # Inverted logic for pull-up
            
            self.get_logger().info("GPIO setup completed")
            
        except Exception as e:
            self.get_logger().error(f"GPIO setup failed: {e}")
            raise
    
    def _pulse_callback(self, channel):
        """
        Handle rotary encoder pulse events (CLK/DT pin changes)

        This implements the same logic as the original Rotary.py __pulse method
        """

        try:
            clk_state = self.gpio.read_pin(self.clk_pin)
            dt_state = self.gpio.read_pin(self.dt_pin)

            self.get_logger().debug(f"Pulse callback: channel={channel}, CLK={clk_state}, DT={dt_state}, last_state={self.rotary_last_state}")

            with self.state_lock:
                if clk_state != self.rotary_last_state:
                    self.rotary_last_state = clk_state

                    # Simplified rotation detection - detect on every CLK falling edge
                    if clk_state == 0:  # CLK falling edge
                        # Determine rotation direction
                        if dt_state != clk_state:
                            direction = -1  # Counter-clockwise
                            self.encoder_position -= 1
                        else:
                            direction = 1   # Clockwise
                            self.encoder_position += 1

                        self.get_logger().info(f"Rotation detected: direction={direction}, position={self.encoder_position}")

                        # Publish rotation event
                        self._publish_rotation_event(direction)
                        
        except Exception as e:
            self.get_logger().error(f"Pulse callback error: {e}")
    
    def _button_callback(self, channel):
        """
        Handle button press events

        This implements the same logic as the original Rotary.py __button method
        """

        try:
            with self.state_lock:
                current_state = self.gpio.read_pin(self.btn_pin)
                self.button_pressed = not current_state  # Inverted logic for pull-up
                
                # Publish button press event
                self._publish_button_event()
                
        except Exception as e:
            self.get_logger().error(f"Button callback error: {e}")
    
    def _publish_rotation_event(self, direction: int):
        """
        Publish a rotation event
        
        Args:
            direction: Rotation direction (-1 for CCW, +1 for CW)
        """
        msg = RotaryEncoderEvent()
        msg.timestamp = self.get_clock().now().to_msg()
        msg.event_type = RotaryEncoderEvent.EVENT_TYPE_ROTATION
        msg.direction = direction
        msg.button_pressed = self.button_pressed
        msg.encoder_position = self.encoder_position
        
        self.encoder_publisher.publish(msg)
        
        self.get_logger().debug(f"Published rotation event: direction={direction}, position={self.encoder_position}")
    
    def _publish_button_event(self):
        """Publish a button press event"""
        msg = RotaryEncoderEvent()
        msg.timestamp = self.get_clock().now().to_msg()
        msg.event_type = RotaryEncoderEvent.EVENT_TYPE_BUTTON_PRESS
        msg.direction = 0  # Not applicable for button events
        msg.button_pressed = self.button_pressed
        msg.encoder_position = self.encoder_position
        
        self.encoder_publisher.publish(msg)
        
        self.get_logger().info(f"Published button event: pressed={self.button_pressed}")
    
    def _publish_status(self):
        """Publish periodic status updates (for debugging/monitoring)"""
        # This is optional - only publish if there are subscribers
        if self.encoder_publisher.get_subscription_count() > 0:
            with self.state_lock:
                current_button_state = self.gpio.read_pin(self.btn_pin)
                current_button_pressed = not current_button_state
                
                # Only publish if button state changed
                if current_button_pressed != self.button_pressed:
                    self.button_pressed = current_button_pressed
                    event_type = (RotaryEncoderEvent.EVENT_TYPE_BUTTON_PRESS if current_button_pressed 
                                else RotaryEncoderEvent.EVENT_TYPE_BUTTON_RELEASE)
                    
                    msg = RotaryEncoderEvent()
                    msg.timestamp = self.get_clock().now().to_msg()
                    msg.event_type = event_type
                    msg.direction = 0
                    msg.button_pressed = self.button_pressed
                    msg.encoder_position = self.encoder_position
                    
                    self.encoder_publisher.publish(msg)
                    
                    self.get_logger().debug(f"Status update: button_pressed={self.button_pressed}")
    
    def get_encoder_position(self) -> int:
        """
        Get current encoder position
        
        Returns:
            Current encoder position
        """
        with self.state_lock:
            return self.encoder_position
    
    def reset_encoder_position(self):
        """Reset encoder position to zero"""
        with self.state_lock:
            self.encoder_position = 0
            self.get_logger().info("Encoder position reset to zero")
    
    def destroy_node(self):
        """Clean up resources when node is destroyed"""
        try:
            self.get_logger().info("Shutting down Rotary Encoder Node")
            
            # Remove event detection
            self.gpio.remove_event_detect(self.clk_pin)
            self.gpio.remove_event_detect(self.dt_pin)
            self.gpio.remove_event_detect(self.btn_pin)
            
            # Cleanup GPIO
            self.gpio.cleanup()
            
        except Exception as e:
            self.get_logger().error(f"Error during cleanup: {e}")
        
        super().destroy_node()


def main(args=None):
    """Main entry point for the rotary encoder node"""
    rclpy.init(args=args)
    
    try:
        node = RotaryEncoderNode()
        
        # Use MultiThreadedExecutor for better callback handling
        from rclpy.executors import MultiThreadedExecutor
        executor = MultiThreadedExecutor()
        
        try:
            rclpy.spin(node, executor=executor)
        except KeyboardInterrupt:
            node.get_logger().info("Keyboard interrupt received")
        finally:
            node.destroy_node()
            
    except Exception as e:
        print(f"Failed to start rotary encoder node: {e}")
        return 1
    
    finally:
        try:
            rclpy.shutdown()
        except:
            pass
    
    return 0


if __name__ == '__main__':
    exit(main())

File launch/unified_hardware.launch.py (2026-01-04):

#!/usr/bin/env python3
"""
Unified Hardware Launch File for ChessMate

Cross-platform launch configuration for Linux host or Raspberry Pi deployment.
User must explicitly specify the platform and hardware mode.

Features:
- User-specified platform and hardware mode
- Conditional node launching based on platform
- Unified parameter loading
- Hardware testing integration
- Mock mode support for development

Usage:
  # For Raspberry Pi with real hardware
  ros2 launch chessmate_hardware unified_hardware.launch.py platform:=raspberry_pi hardware_mode:=real

  # For development machine with mock hardware
  ros2 launch chessmate_hardware unified_hardware.launch.py platform:=linux_host hardware_mode:=mock

  # With different log levels
  ros2 launch chessmate_hardware unified_hardware.launch.py platform:=raspberry_pi hardware_mode:=real log_level:=DEBUG
  ros2 launch chessmate_hardware unified_hardware.launch.py platform:=raspberry_pi hardware_mode:=real log_level:=ERROR
"""

import os
from launch import LaunchDescription
from launch.actions import DeclareLaunchArgument, OpaqueFunction
from launch.substitutions import LaunchConfiguration, TextSubstitution
from launch_ros.actions import Node
from launch.conditions import IfCondition, UnlessCondition
from ament_index_python.packages import get_package_share_directory





def generate_launch_description():
    """Generate launch description based on platform and configuration"""
    
    # Get package directory
    pkg_dir = get_package_share_directory('chessmate')
    config_file = os.path.join(pkg_dir, 'config', 'unified_hardware_config.yaml')
    
    # Declare launch arguments
    declared_arguments = [
        DeclareLaunchArgument(
            'platform',
            default_value='raspberry_pi',
            description='Target platform: linux_host, raspberry_pi, or mock (user must specify)'
        ),
        DeclareLaunchArgument(
            'config_file',
            default_value=config_file,
            description='Path to hardware configuration file'
        ),
        DeclareLaunchArgument(
            'hardware_mode',
            default_value='real',
            description='Hardware mode: real, mock, or simulation'
        ),
        DeclareLaunchArgument(
            'enable_testing',
            default_value='false',
            description='Enable hardware testing nodes'
        ),
        DeclareLaunchArgument(
            'auto_calibrate',
            default_value='false',
            description='Automatically calibrate on startup'
        ),
        DeclareLaunchArgument(
            'log_level',
            default_value='info',
            description='Logging level: debug, info, warn, error'
        ),
    ]
    
    # Launch configuration
    platform = LaunchConfiguration('platform')
    config_file_arg = LaunchConfiguration('config_file')
    hardware_mode = LaunchConfiguration('hardware_mode')
    enable_testing = LaunchConfiguration('enable_testing')
    auto_calibrate = LaunchConfiguration('auto_calibrate')
    log_level = LaunchConfiguration('log_level')
    
    def launch_setup(context, *args, **kwargs):
        """Setup launch based on context"""
        
        platform_value = context.launch_configurations['platform']
        hardware_mode_value = context.launch_configurations['hardware_mode']
        enable_testing_value = context.launch_configurations['enable_testing']
        
        nodes = []
        
        # Common parameters for all nodes
        use_mock_hardware = hardware_mode_value in ['mock', 'simulation']
        common_parameters = [
            config_file_arg,
            {'platform_override': platform_value},
            {'hardware_mode': hardware_mode_value},
            {'use_mock_hardware': use_mock_hardware},
            {'auto_calibrate': auto_calibrate},
        ]
        
        # Core hardware nodes (always launched)
        
        # Unified Arduino Bridge (replaces arduino_communication_node)
        nodes.append(
            Node(
                package='chessmate',
                executable='unified_arduino_bridge',
                name='unified_arduino_bridge',
                parameters=common_parameters,
                arguments=['--ros-args', '--log-level', log_level],
                output='screen'
            )
        )
        
        # Game Management Node
        nodes.append(
            Node(
                package='chessmate',
                executable='game_management_node',
                name='game_management_node',
                parameters=common_parameters,
                arguments=['--ros-args', '--log-level', log_level],
                output='screen'
            )
        )
        
        # Robot Animation Controller
        nodes.append(
            Node(
                package='chessmate',
                executable='robot_animation_controller',
                name='robot_animation_controller',
                parameters=common_parameters,
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

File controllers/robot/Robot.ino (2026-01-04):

// Copyright (c) 2025 Vipin M
// Licensed under the MIT License. See LICENSE file in the project root for full license information.

#include "Arm.h"
#include "Head.h"

animation_id_t animation_id;

// New USB communication variables
bool mock_mode = true;  // Default to mock mode for testing
String pending_command = "";
unsigned long mock_move_start_time = 0;
unsigned long mock_move_duration = 0;
bool mock_move_in_progress = false;

// Robot state enumeration
typedef enum {
  ROBOT_IDLE,
  ROBOT_INITIALIZING,
  ROBOT_HOMING,
  ROBOT_MOVING,
  ROBOT_ERROR
} robot_state_t;

robot_state_t robot_state = ROBOT_IDLE;

void setup()
{
  Serial.begin(9600);

  // Wait for USB Serial connection
  for (uint16_t trial = 0; trial < 2000; trial++) {
    if (Serial) {
      break;
    }
  }

  head_init();
  arm_init();

  Serial.println("ROBOT: ChessMate Robot Controller initialized");
  Serial.print("ROBOT: Default mode is ");
  Serial.println(mock_mode ? "MOCK" : "REAL");
  Serial.println("ROBOT: Ready for commands");
}

void loop() {
  // Process USB commands first
  scan_usb_serial();

  // Process mock mode simulation
  if (mock_mode) {
    process_mock_mode();
  }

  // Original functionality
  arm_run();
  animate();
}

// USB Serial Communication Functions
void scan_usb_serial() {
  if (Serial.available()) {
    String input = Serial.readStringUntil('\n');
    input.trim();

    if (input.length() > 0) {
      process_usb_command(input);
    }
  }
}

void process_usb_command(String command) {
  Serial.print("ROBOT: Received command: ");
  Serial.println(command);

  // Parse command type
  if (command.startsWith("mode:")) {
    handle_mode_command(command);
  } else if (command == "init") {
    handle_init_command();
  } else if (command == "home") {
    handle_home_command();
  } else if (command == "status") {
    handle_status_command();
  } else if (command.length() == 6 && is_valid_move(command)) {
    handle_move_command(command);
  } else if (command.length() == 1) {
    handle_single_char_command(command.charAt(0));
  } else {
    Serial.print("ROBOT: Unknown command: ");
    Serial.println(command);
  }
}

void handle_mode_command(String command) {
  String mode = command.substring(5);  // Remove "mode:"

  if (mode == "mock") {
    mock_mode = true;
    Serial.println("ROBOT: Mock simulation mode enabled");
  } else if (mode == "real") {
    mock_mode = false;
    Serial.println("ROBOT: Real hardware mode enabled");
  } else {
    Serial.print("ROBOT: Unknown mode: ");
    Serial.println(mode);
    return;
  }

  Serial.print("ROBOT: Current mode is ");
  Serial.println(mock_mode ? "MOCK" : "REAL");
}

void handle_init_command() {
  robot_state = ROBOT_INITIALIZING;
  Serial.println("ROBOT: Initializing robot systems");

  if (mock_mode) {
    // Mock initialization
    Serial.println("ROBOT: Mock initialization complete");
    robot_state = ROBOT_IDLE;
  } else {
    // Real hardware initialization (already done in setup)
    Serial.println("ROBOT: Real hardware initialization complete");
    robot_state = ROBOT_IDLE;
  }
}

void handle_home_command() {
  robot_state = ROBOT_HOMING;
  Serial.println("ROBOT: Homing robot to origin position");

  if (mock_mode) {
    // Mock homing
    Serial.println("ROBOT: Mock homing complete");
    robot_state = ROBOT_IDLE;
  } else {
    // Real hardware homing
    home_all();
    curl_up();
    Serial.println("ROBOT: Real hardware homing complete");
    robot_state = ROBOT_IDLE;
  }
}

void handle_status_command() {
  Serial.print("ROBOT: Status - State: ");
  Serial.print(get_state_name(robot_state));
  Serial.print(", Mode: ");
  Serial.print(mock_mode ? "MOCK" : "REAL");

  if (mock_move_in_progress) {
    unsigned long elapsed = millis() - mock_move_start_time;
    Serial.print(", Move Progress: ");
    Serial.print((elapsed * 100) / mock_move_duration);
    Serial.print("%");
  }

  Serial.println();
}

void handle_move_command(String move) {
  if (robot_state != ROBOT_IDLE) {
    Serial.print("ROBOT: Cannot execute move, robot busy (state: ");
    Serial.print(get_state_name(robot_state));
    Serial.println(")");
    return;
  }

  pending_command = move;
  robot_state = ROBOT_MOVING;

  Serial.print("ROBOT: Executing move: ");
  Serial.println(move);

  if (mock_mode) {
    start_mock_move(move);
  } else {
    // Execute real hardware move using existing execute_move function
    execute_move(move);
    robot_state = ROBOT_IDLE;
    Serial.print("ROBOT: Move completed: ");
    Serial.println(move);
    Serial.println("ROBOT: Ready for next command");
  }
}

void handle_single_char_command(char cmd) {
  switch (cmd) {
    case 'i':
      Serial.println("ROBOT: Wake up command received");
      animation_id = WAKE_UP;
      break;
    case 's':
      Serial.println("ROBOT: Sleep command received");
      animation_id = DOZE_OFF;
      break;
    case 'j':
      handle_home_command();
      break;
    case 'z':
      handle_home_command();
      break;
    default:
      Serial.print("ROBOT: Unknown single character command: ");
      Serial.println(cmd);
      break;
  }
}

// Mock mode functions
void process_mock_mode() {
  if (!mock_mode || !mock_move_in_progress) {
    return;
  }

  unsigned long elapsed = millis() - mock_move_start_time;

  if (elapsed >= mock_move_duration) {
    // Mock move completed
    mock_move_in_progress = false;
    robot_state = ROBOT_IDLE;

    Serial.print("ROBOT: Move completed: ");
    Serial.println(pending_command);
    Serial.println("ROBOT: Ready for next command");

    pending_command = "";
  }
}

void start_mock_move(String move) {
  mock_move_start_time = millis();
  mock_move_duration = random(3000, 8000);  // 3-8 seconds
  mock_move_in_progress = true;

  Serial.print("ROBOT: Starting mock move, estimated duration: ");
  Serial.print(mock_move_duration);
  Serial.println("ms");
}

// Validation functions
bool is_valid_move(String move) {
  // Basic validation for 6-character move format: e2pe4p
  if (move.length() != 6) return false;

  // Check source square (chars 0-1: "e2")
  if (!is_valid_square(move.substring(0, 2))) return false;

  // Check destination square (chars 3-4: "e4")
  if (!is_valid_square(move.substring(3, 5))) return false;

  // Check piece characters (char 2: source piece, char 5: dest piece)
  if (!is_valid_piece(move.charAt(2))) return false;
  if (!is_valid_piece(move.charAt(5)) && move.charAt(5) != 'x') return false;

  return true;
}

bool is_valid_square(String square) {
  if (square.length() != 2) return false;

  char file = square.charAt(0);
  char rank = square.charAt(1);

  return (file >= 'a' && file <= 'h') && (rank >= '1' && rank <= '8');
}

bool is_valid_piece(char piece) {
  return (piece == 'p' || piece == 'r' || piece == 'n' ||
          piece == 'b' || piece == 'q' || piece == 'k');
}
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

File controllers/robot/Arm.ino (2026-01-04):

// Copyright (c) 2025 Vipin M
// Licensed under the MIT License. See LICENSE file in the project root for full license information.

#include <AccelStepper.h>
#include <MultiStepper.h>
#include <Servo.h>
#include <assert.h>
#include <math.h>
#include <EEPROM.h>
#include <SoftwareSerial.h>

#undef MULTISTEPPER_ENABLED //change to #undef if we want the motors to accelerate/decelerate

#define STEPPER_X_STP_PIN 2
#define STEPPER_Y_STP_PIN 3 
#define STEPPER_Z_STP_PIN 4
#define STEPPER_X_DIR_PIN 5 
#define STEPPER_Y_DIR_PIN 6
#define STEPPER_Z_DIR_PIN 7
#define STEPPER_ENABLE_PIN 8
#define LIMIT_SWITCH_X_PIN 9
#define LIMIT_SWITCH_Y_PIN 10
#define LIMIT_SWITCH_Z_PIN 11
#define SERIAL_RX_PIN 12
#define SERIAL_TX_PIN A3

#define GRIPPER_SERVO_PIN 13
#define GRIPPER_OPEN_ANGLE 20
#define GRIPPER_CLOSE_ANGLE 100

#define MOTOR_INTERFACE_TYPE 1

#define ARM_1_SIZE 202.0f // mm
#define ARM_2_SIZE 190.0f // mm
#define LOWER_LEFT_CORNER_X -116.65 // origin at base
#define LOWER_LEFT_CORNER_Y 137.0
#define UPPER_LEFT_CORNER_X -116.65
#define UPPER_LEFT_CORNER_Y 370.33 // 137 + 233.33
#define UPPER_RIGHT_CORNER_X 116.65
#define UPPER_RIGHT_CORNER_Y 370.33
#define LOWER_RIGHT_CORNER_X 116.65
#define LOWER_RIGHT_CORNER_Y 137.0
#define CHESS_ROWS 8
#define CHESS_COLS 8

#define EEPROM_START_ADDRESS 0
#define ANGLE_DATA_SIZE 8 // bytes per square

#define MAX_SPEED_X 2500
#define REDUCED_SPEED_X (MAX_SPEED_X >> 1)
#define HOMING_SPEED_X (-MAX_SPEED_X)
#define HOMING_REDUCED_SPEED_X (-(MAX_SPEED_X >> 3))
#define ACCELERATION_X 2000

#define MAX_SPEED_Y 3500
#define REDUCED_SPEED_Y (MAX_SPEED_Y >> 1)
#define HOMING_SPEED_Y (-MAX_SPEED_Y)
#define HOMING_REDUCED_SPEED_Y (-(MAX_SPEED_Y >> 3))
#define ACCELERATION_Y 2000

#define MAX_SPEED_Z 1200
#define REDUCED_SPEED_Z (MAX_SPEED_Z >> 1)
#define HOMING_SPEED_Z (-REDUCED_SPEED_Z)
#define HOMING_REDUCED_SPEED_Z (-(MAX_SPEED_Z >> 1))
#define ACCELERATION_Z 1500
#define Z_MIN 200
#define Z_LOW 500
#define Z_MAX 2500

#define Z_MIN_PAWN_OFFSET 0
#define Z_MIN_ROOK_OFFSET 25
#define Z_MIN_KNIGHT_OFFSET -100
#define Z_MIN_BISHOP_OFFSET 150
#define Z_MIN_QUEEN_OFFSET 300
#define Z_MIN_KING_OFFSET 300

#define PULLEY_RATIO 1.00 //1.879
#define STEPS_REF_X 820
#define STEPS_REF_Y 7720
#define STEPS_PER_DEGREE_X 64.0f // 72/20 (gear down ratio) * 200 (steps per revolution) * 32 (microstepping) / 360 (degrees)
#define STEPS_PER_DEGREE_Y 55.11f // 62/20 (gear down ratio 1) * 62/62 (gear down ratio 2) * 200 * 32 / 360
#define STEPS_CNT(_deg, _dir) \
  ((_deg * STEPS_PER_DEGREE_##_dir) + STEPS_REF_##_dir)
#define STEP_ZERO_ANGLE(_dir) \
  (-STEPS_REF_##_dir / STEPS_PER_DEGREE_##_dir)

#define CAL_LARGE_STEP 5.0
#define CAL_SMALL_STEP 0.5

SoftwareSerial chessboard(SERIAL_RX_PIN, SERIAL_TX_PIN);

uint32_t z_min[PIECE_TYPE_NUM] = {
  Z_MIN + Z_MIN_PAWN_OFFSET,
  Z_MIN + Z_MIN_ROOK_OFFSET,
  Z_MIN + Z_MIN_KNIGHT_OFFSET,
  Z_MIN + Z_MIN_BISHOP_OFFSET,
  Z_MIN + Z_MIN_QUEEN_OFFSET,
  Z_MIN + Z_MIN_KING_OFFSET,
};

AccelStepper stepperX = AccelStepper(MOTOR_INTERFACE_TYPE, STEPPER_X_STP_PIN, STEPPER_X_DIR_PIN);  
AccelStepper stepperY = AccelStepper(MOTOR_INTERFACE_TYPE, STEPPER_Y_STP_PIN, STEPPER_Y_DIR_PIN);  
AccelStepper stepperZ = AccelStepper(MOTOR_INTERFACE_TYPE, STEPPER_Z_STP_PIN, STEPPER_Z_DIR_PIN);  

MultiStepper multistepper;
long multistepper_positions[2];
Servo gripper;
double angle1 = 0.0;
double angle2 = 0.0;
int current_square_index; // From 0 to 63 for the 64 squares

struct grid {
  double x;
  double y;
} corner[] = {
  {LOWER_LEFT_CORNER_X,LOWER_LEFT_CORNER_Y},
  {UPPER_LEFT_CORNER_X,UPPER_LEFT_CORNER_Y},
  {UPPER_RIGHT_CORNER_X,UPPER_RIGHT_CORNER_Y},
  {LOWER_RIGHT_CORNER_X,LOWER_RIGHT_CORNER_Y},
};

void gripper_close()
{
  gripper.write(GRIPPER_CLOSE_ANGLE); 
}

void gripper_open()
{
  gripper.write(GRIPPER_OPEN_ANGLE);
}

void move_xy_to(double x_deg, double y_deg)
{
  long x_steps = STEPS_CNT(x_deg, X);
  long y_steps = STEPS_CNT(y_deg, Y);
  //Serial.print(x_steps);
  //Serial.print(", ");
  //Serial.println(y_steps);

#ifdef MULTISTEPPER_ENABLED
  multistepper_positions[0] = x_steps;
  multistepper_positions[1] = y_steps;
  multistepper.moveTo(multistepper_positions);
  multistepper.runSpeedToPosition(); // Blocks until all are in position
#else
  stepperX.moveTo(x_steps);
  stepperY.moveTo(y_steps);
  while ((stepperX.currentPosition() != x_steps) || (stepperY.currentPosition() != y_steps)) {
    stepperX.run();
    stepperY.run();
    animate();
  }
#endif
}

void move_x_to(double degree)
{
  long steps = STEPS_CNT(degree, X);
  stepperX.moveTo(steps);
  while (stepperX.currentPosition() != steps) {
    stepperX.run();
    animate();
  }
}

void move_y_to(double degree)
{
  long steps = STEPS_CNT(degree, Y);
  stepperY.moveTo(steps);
  while (stepperY.currentPosition() != steps) {
    stepperY.run();
    animate();
  }
}

void move_z_to(long steps)
{
  stepperZ.moveTo(steps);
  while (stepperZ.currentPosition() != steps) {
    stepperZ.run();
  }
}

void home_x()
{
  // Search mode - move quickly until the limit switch is triggered
  stepperX.setSpeed(HOMING_SPEED_X);
  while (!digitalRead(LIMIT_SWITCH_X_PIN)) {
    stepperX.runSpeed();
  }
  stepperX.stop();

  // Locate mode - move slowly away from the switch and then back to engage it slowly
  stepperX.move(200); // Move 100 steps away
  while (stepperX.distanceToGo() > 0) {
    stepperX.run();
  }
  delay(100);
  stepperX.setSpeed(HOMING_REDUCED_SPEED_X); // Move back towards the switch slowly
  while (!digitalRead(LIMIT_SWITCH_X_PIN)) {
    stepperX.runSpeed();
  }
  stepperX.stop();

  // Pull-off motion - move away from the limit switch to disengage it
  stepperX.move(50); // Move away from the switch to disengage
  while (stepperX.distanceToGo() > 0) {
    stepperX.run();
  }

  stepperX.setCurrentPosition(0); // When limit switch pressed set position to 0 steps
}

void home_y()
{
 // Search mode - move quickly until the limit switch is triggered
  stepperY.setSpeed(HOMING_SPEED_Y);
  while (!digitalRead(LIMIT_SWITCH_Y_PIN)) {
    stepperY.runSpeed();
  }
  stepperY.stop();

  // Locate mode - move slowly away from the switch and then back to engage it slowly
  stepperY.move(200); // Move 100 steps away
  while (stepperY.distanceToGo() > 0) {
    stepperY.run();
  }
  delay(100);
  stepperY.setSpeed(HOMING_REDUCED_SPEED_Y); // Move back towards the switch slowly
  while (!digitalRead(LIMIT_SWITCH_Y_PIN)) {
    stepperY.runSpeed();
  }
  stepperY.stop();

  // Pull-off motion - move away from the limit switch to disengage it
  stepperY.move(50); // Move away from the switch to disengage
  while (stepperY.distanceToGo() > 0) {
    stepperY.run();
  }

  stepperY.setCurrentPosition(0); // When limit switch pressed set position to 0 steps
}
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

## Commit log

2024-01-14 Add Arduino code
2024-01-15 Refactor the Arduino code
2024-01-15 Add button support
2024-01-15 Add support for LEDs indicating turn
2024-01-16 Add cmds, fix memory issues & general cleanup
    [Button.ino, ChessBoard.ino, Display.ino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]
2024-01-18 Cleanup button code and tighten up state checks
    [Button.ino, Display.ino, Sensor.ino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]
2024-01-18 Add indication for fatal error
    [Display.ino, Serial.ino]
2024-01-18 Add support for LED indicating player's turn
2024-01-19 Add support for 'hint' on the board
2024-01-19 Refactor code to move some complexity out of sensor scan
2024-01-20 Add a WAR for the initial ghost button press
2024-01-20 Fix an issue with tracking the stick add/remove
    [ChessBoard.ino, Sensor.ino, Serial.ino]
2024-01-21 Add support for manual overrides on the board
2024-02-11 Transition to pico (from nano), extend to 8x8 board
2026-01-04 Fix a broken test
    [unified_hardware_config.yaml]
2026-01-04 Consolidate into single package
    [base_link_collision.stl, base_link_visual.stl, chess_board.urdf.xacro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]
2026-01-04 Use device names from udev specs
2026-01-04 Flatten workspace
    [base_link_collision.stl, base_link_visual.stl, chess_board.urdf.xacro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]
2026-01-18 Use bash shebang for stages that source ROS setup
